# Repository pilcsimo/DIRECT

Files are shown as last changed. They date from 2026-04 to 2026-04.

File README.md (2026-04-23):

# DIRECT: Durable Intuitive Repeatable Ergonomic Control Device for Robot Teleoperation

This is the SW and HW repository of DIRECT. Visit the [website](https://pilcsimo.github.io/direct/index.html) for the paper and supplementary material.

DIRECT is an active teleoperation leader arm designed for continuous, large-scale robot data collection with [DROID](https://droid-dataset.github.io/). It serves as a drop-in alternative to VR controllers, offering a more intuitive experience for operators familiar with robot arms.

DIRECT builds on the hardware and software foundations of [FACTR](https://jasonjzliu.com/factr/) and draws mechanical inspiration from [GELLO](https://wuphilipp.github.io/gello_site/). It addresses three pain points encountered during sustained data collection: mechanical failures under continuous use, calibration drift between sessions, and operator fatigue during standing workflows.

> **Credits:**
> - Software and control architecture based on **FACTR** by Jason Jingzhou Liu and Yulong Li.
>   - Teleop software: [github.com/JasonJZLiu/FACTR_Teleop](https://github.com/JasonJZLiu/FACTR_Teleop)
>   - Hardware design: [github.com/JasonJZLiu/FACTR_Hardware](https://github.com/JasonJZLiu/FACTR_Hardware)
> - Mechanical gripper inspiration from **GELLO** by Philipp Wu et al.: [github.com/wuphilipp/gello_mechanical](https://github.com/wuphilipp/gello_mechanical)

---

## DIRECT Design

DIRECT prioritizes three principles for continuous data collection:

### Durability via Servo Shields

Active joint-space controllers that mount servos as load-bearing elements are vulnerable to thread pull-out, where mounting screws tear from the plastic servo housings under continuous use. DIRECT introduces 3D-printed enclosures that absorb and redirect structural loads away from the servos. Mechanical failures observed during testing occurred exclusively on 3D-printed parts, which can be reprinted on demand.

### Repeatability via Deterministic Calibration

Prior puppet-style controllers rely on a visual resting pose for calibration, which can drift between sessions and cause unstable gravity compensation. DIRECT introduces physical calibration fixtures that lock the device joints into a mechanical zero. The physical joint configuration at startup therefore matches the zero pose defined in the URDF, providing consistent initial conditions across episodes.

### Ergonomics for Standing Operation

DIRECT raises the base by 10 cm to extend the operator's reachable configuration space during the standing workflow typical of DROID. It also introduces the **Ergogrip** — a contoured handle inspired by lever-action grips — designed for single-handed standing operation during extended sessions.

### Printability and Sourcing

All structural parts are designed for 3D printing in PETG for improved toughness and temperature resistance. Pre-configured print files with correct part orientations are provided. The design uses standard screws included with the servos and an off-the-shelf metric ball bearing.

### Software Architecture

DIRECT uses a decoupled two-process architecture to integrate into data collection platforms without modifying their codebases. A standalone Python application runs a 500 Hz control loop managing device kinematics and gravity compensation. A lightweight plugin runs alongside the platform GUI, translating device states into joint commands. A de-sync state machine handles reconnection after trajectory resets: each reconnection triggers a smooth PD realignment before active control resumes.

### Force Feedback

Full bi-directional force feedback (as in FACTR) requires a tight control loop at hundreds of Hz between robot and device. Routing this through the DROID GUI (~50 Hz) introduces latency that destabilizes the loop. DIRECT therefore does not implement force feedback in this release. Instead, a local virtual spring on the device trigger provides passive resistance for grip comfort.

---

## Hardware

> **Assembly guide:** DIRECT does not yet have its own assembly documentation. Follow the **[FACTR Hardware assembly guide](https://github.com/JasonJZLiu/FACTR_Hardware)** (core arm structure, servo wiring, and BOM). The DIRECT-specific printed parts are drop-in additions that are self-explanatory once you have the base arm assembled.

DIRECT-specific parts are available in `hardware/`:
- **`hardware/step/`** — STEP (`.step`) source CAD files, for import into any CAD tool
- **`hardware/3mf/`** — 3MF (`.3mf`) print files pre-configured in **PrusaSlicer** with correct part orientations, supports, and material settings

Parts included:
- Servo shield enclosures — redirect structural loads away from servo housings
- Calibration fixtures (base wedge + joint wedge + trigger dock) — lock joints into mechanical zero
- Elevated base (+10 cm) — extends the operator's reachable configuration space
- Ergogrip handle — contoured for single-handed standing operation

All DIRECT parts are designed for **PETG** (recommended over PLA for toughness and temperature resistance). Pre-configured print orientations are included in the 3MF files. The design uses M2/M3 screws (included with the servos) and one standard metric ball bearing.

> **Important — weigh links before assembly:** `direct.urdf` encodes the mass and inertia of each link *with its servo already installed*. Weigh each printed link after inserting its servo (and any heat-set inserts/bearings) but *before* attaching it to the arm chain. Update the corresponding `<mass value="..."/>` entries in the URDF to match your measured values. Accurate link masses are critical for stable gravity compensation.
>
> **Note on URDF provenance:** The mass and inertia parameters in `direct.urdf` are taken directly from the FACTR project and have **not** been re-measured or recalculated for DIRECT. This means gravity compensation may exhibit some residual drift even after accurate mechanical calibration. If you require tighter gravity compensation, re-identify the link inertial parameters for your specific assembly.

---

## First Time Installation Guide

### Hardware Setup

- Follow the [FACTR Hardware assembly guide](https://github.com/JasonJZLiu/FACTR_Hardware) to build the base arm, then add the DIRECT-specific printed parts.
- Install DIRECT onto your DROID portable setup (power sources, USB, mounting via clamps/screws, cable management).
- Verify the device powers on and servos respond before proceeding.

### Software Setup — DROID's Data Collection Laptop

> Requires DROID to already be installed. If not, follow [droid-dataset.github.io](https://droid-dataset.github.io/) first.

Create a dedicated Conda environment with Python 3.10 to avoid dependency conflicts with the DROID GUI environment:

```bash
conda create -n teleop_direct python=3.10
conda activate teleop_direct
```

Follow the [Dynamixel servo setup guide](./src/direct/README.md) to configure servo IDs, baud rates, and USB latency.

Install [Pinocchio](https://stack-of-tasks.github.io/pinocchio/download.html) and then clone and install this package at the same level as the DROID repository:

```bash
conda activate teleop_direct
cd <path_to_repo_root>/DIRECT
pip install -e .
```

---

## Testing Before Using with DROID

Make sure the DIRECT device is powered on and connected to your laptop via USB.

```bash
conda activate teleop_direct
python DIRECT/scripts/run_direct.py --calib  # required on first run or after re-powering servos
```

This launches the DIRECT control loop and connects to the device. Follow the terminal prompts to calibrate. This process must be launched **before** the DROID GUI.

---

# Usage with DROID GUI — Teleoperator's Guide

## DIRECT Hardware Setup

- Plug DIRECT into the power outlet (white cable).
- Turn ON the switch on the blue Servo Control Board (mounted to the base of DIRECT). A red LED should illuminate, indicating servos are powered.
- Plug the Micro-USB cable from the PC into the Servo Control Board (U2D2 converter). A second red LED inside the box should illuminate, indicating USB connection.

## DIRECT Calibration

Before starting the DROID GUI, DIRECT must be calibrated. Insert the calibration fixtures to lock the device into its mechanical zero position, which corresponds to the Franka Emika Panda robot arm zero pose.

The compound figure below shows the device fully assembled with all calibration fixtures inserted, from three angles:

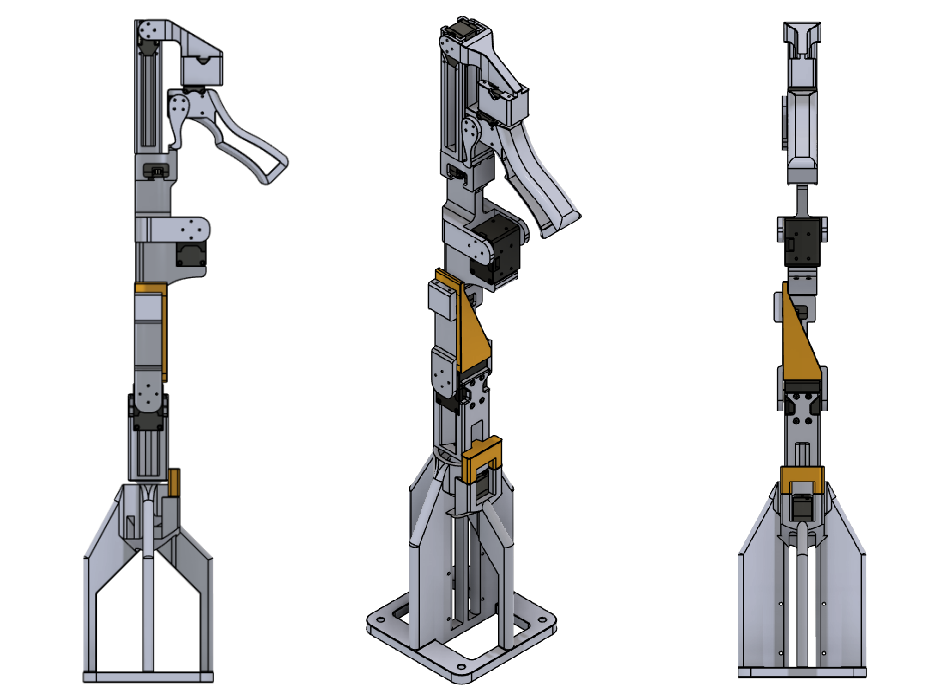
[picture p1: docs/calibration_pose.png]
DIRECT in calibration (zero) position — front, side, and 3/4 views


> **Wrist camera:** The wrist-mounted camera mounts on the **side of the Ergogrip handle**. Ensure it is attached before calibrating so its cable routing does not shift the device out of the locked position.

Fixtures to insert before calibrating:
- **Base wedge** (black) — locks the base joint
- **Joint wedge** (orange) — inserted between links to lock the mid-chain joints
- **Trigger dock** — trigger rested against the notch on link 4 (small white arrow marker)

Open the 1st terminal and run:

```bash
conda activate teleop_direct
python DIRECT/scripts/run_direct.py --calib  # IMPORTANT: --calib is required every time servo power is cycled
```

The script will exit with an error if the USB latency timer is not set. Follow the printed instruction to fix it (needs `sudo`):

```bash
echo 1 | sudo tee /sys/bus/usb-serial/devices/ttyUSB0/latency_timer
```

Run the calibration command again after setting the timer. This is required every time servo power is cycled.

Calibration procedure:
1. Insert the calibration fixtures as shown above — this locks the device into its mechanical zero.
2. Press **Enter** at the first prompt. Remove the calibration fixtures.
3. At the second prompt you set the null-space (redundancy resolution) target. Position the device where desired, then press **Enter**. DIRECT will automatically hold this configuration when redundancy is available.

The calibration is saved to a `.npy` file beside the config. On subsequent runs without `--calib`, the saved calibration is loaded automatically (as long as servo power was not cycled).

## After Calibration — Starting the Control Loop

DIRECT will enter gravity compensation mode automatically after calibration. Leave this terminal running.

To start in a subsequent session (servo power not cycled):

```bash
conda activate teleop_direct
python DIRECT/scripts/run_direct.py
```

---

## Dry-Run — Test DIRECT Without the Robot

Before launching the full DROID GUI (which sends live commands to the Franka), you can dry-run the policy to verify DIRECT is communicating correctly and the policy initialises without errors:

```bash
conda activate teleop_direct
python DIRECT/scripts/debug_direct_policy.py
```

This script initialises `DIRECTTeleopPolicy` and loops `policy.forward()` at 10 Hz using a fixed observation set to the DROID Franka rest pose. No robot connection is required. Use it to confirm ZMQ addresses, keyboard handling, and policy state logic before risking live hardware.

---

## Running DROID GUI with DIRECT

Pre-flight checklist:

- Franka robot is powered on (yellow), unlocked (white button glowing blue), and in FCI mode.
- Robot is connected to the Polymetis Control Robot PC.
- All ZED cameras are powered and connected to the Data Collection PC.
- DIRECT control loop is running in the 1st terminal (step above).
- ChArUco calibration board is ready for the DROID camera calibration procedure.

Open a 2nd terminal for the DROID GUI:

```bash
conda activate teleop_droid
python DIRECT/scripts/main.py --direct
```

### Keyboard Controls

| Key | Action |
|-----|---|
| `F5` | Toggle all inputs ON/OFF (lock-out to prevent accidental commands) |
| `A` | Pulse success signal |
| `B` | Pulse failure signal |
| `M` | Toggle movement ON/OFF — enables/disables sending joint commands to robot |
| `N` | Set null-space target to current device position |
| `V` | Toggle torque visualisation |
| `F` | Cycle feedback mode (OFF → ALIGNED_TORQUE) |
| `Shift` | Toggle camera views in DROID GUI |

**When enabling movement (`M`):** DIRECT first syncs to the robot's current position. Do not resist — let it settle before moving. You will feel the device actively move to match the robot; wait until it stops before starting teleoperation.

**When setting null-space (`N`):** DIRECT will automatically drift toward this joint configuration whenever redundancy is available (without moving the end-effector).

### Recording Trajectories

1. Make sure **movement is disabled** first.
2. Press `A` to start recording. Wait for camera feeds and the robot to reach its start position.
3. After camera feeds appear, press `M` to enable movement and begin teleoperation.

---

## Known Issues and Planned Improvements

### Known Issues

- Sync via `M` key can occasionally be unreliable in the DROID GUI — under investigation.
- No end-effector safety workspace — the robot can reach itself or surrounding objects.
- Gripper virtual spring can bounce at the end of its range of motion.

### Planned Improvements

- Force feedback: detect external joint torques on the robot and relay them to the device (framework is present, tuning required).
- End-effector safety bounding box via IK on the DIRECT side.

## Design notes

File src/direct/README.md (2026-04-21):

# Setting up Dynamixel Servos

> **Attribution:** The servo setup instructions below are adapted directly from the
> [FACTR Teleop README](https://github.com/JasonJZLiu/FACTR_Teleop/blob/main/src/factr_teleop/README.md)
> (© FACTR authors, Apache 2.0). Follow that guide through the
> **"Setting up Dynamixel Servos"** section (servo IDs, baud rate, and USB latency).
> **Stop before "Preparing to Launch FACTR Teleop"** — DIRECT uses a different
> calibration and launch procedure. Return to the [main README](../../README.md)
> for those steps.

Before using DIRECT, the leader arm's Dynamixel servos need to be properly
configured. Please install the [Dynamixel Wizard](https://emanual.robotis.com/docs/en/software/dynamixel/dynamixel_wizard2/)
software.

## Update Servo IDs

By default, all Dynamixel servos are set to ID 1. To control multiple servos with a single U2D2 controller,
each servo must be assigned a unique ID. This assignment should be done one servo at a time, starting with
the servo closest to the robot base and progressing up the kinematic chain. Assign IDs sequentially from
1 up to 8, with the gripper trigger servo holding ID 8.

### Steps to Change a Servo's ID

1. **Connect a single servo to the U2D2 controller.**
2. **Launch the Dynamixel Wizard software.**
3. **Configure the scanning settings:**
   - In the top menu bar, go to **Tools → Options**.
   - Under **"Select port to scan"**, ensure all ports are selected.
   - Under **"Select baudrate to scan"**, choose the correct baudrate. The default is **57600 bps**. If unsure, select all available options.
   - Under **"Set ID range to scan"**, you can speed up scanning by limiting the range to **0–15**, unless the servo might already have an ID outside this range.
4. **Click the Scan icon** (magnifying glass with a gear) in the top-left corner.
   - If the servo is found, it will appear in the left panel of the window.
5. **Select the detected servo** from the panel, then click **ID** found in the middle panel of the window.
   - Select the new ID on the right panel of the window and click **Save**.
6. **Repeat** the above steps for each servo.

## Increase Servo Control Frequency

There are additional Dynamixel servo settings that must be changed in order to run the control loop at
a frequency as fast as 500Hz. The steps for each servo are as follows:

### Steps to Increase Servo Control Frequency

1. **Launch the Dynamixel Wizard software** and **scan for servos**.
2. **Select each detected servo** from the left-hand panel.
3. In the middle panel, click **"Baud Rate (Bus)"**:
   - On the right-hand panel, **set the value to 4 Mbps** and click **Save**.
4. In the middle panel, click **"Return Delay Time"**:
   - On the right-hand panel, **set the value to 0** and click **Save**.

In addition to the Dynamixel servo settings, it is crucial to minimize the latency of the USB port connected to the U2D2 controller
to achieve high-frequency control. The latency timer should be set to `1` for optimal performance.

### Steps to Check and Set USB Port Latency

1. **List connected U2D2 devices**:

   ```bash
   ls /dev/serial/by-id/
   ```

   This will show device names for each connected U2D2 controller. For example:

   ```
   usb-FTDI_USB__-__Serial_Converter_FT7WBF8S-if00-port0
   usb-FTDI_USB__-__Serial_Converter_FT951EJA-if00-port0
   ```

   Identify the one corresponding to your **leader arm**. Replace `<device-name>` with the correct name in the next steps.

2. **Resolve the full path to the USB device**:

   ```bash
   readlink -f /dev/serial/by-id/<device-name>
   ```

   This will return something like:

   ```
   /dev/ttyUSB0
   ```

3. **Check the current latency timer value**:

   ```bash
   cat /sys/bus/usb-serial/devices/<ttyUSBx>/latency_timer
   ```

   Replace `<ttyUSBx>` with the ttyUSB device name from the previous step (e.g., `ttyUSB0`).

4. **If the value is not `1`, set it manually**:

   ```bash
   echo 1 | sudo tee /sys/bus/usb-serial/devices/<ttyUSBx>/latency_timer
   ```

   > **Note:** This command requires `sudo` permissions.

   > **Note:** Everytime the U2D2 controller USB is re-plugged into the computer, this command needs to be run again to ensure the
   latency timer is 1.

### Automated Latency Check

Note that the provided leader arm node **automatically checks** the latency timer on startup.
It reads the `dynamixel_port` from the YAML config file and verifies that the latency timer is set to `1`.

If the latency is not correctly set, the script will:

- Raise an exception
- Output the exact `echo` command required to fix it

Since changing the latency timer requires `sudo` permissions, **you must run the command manually** when prompted.

---

For configuration, calibration, and usage instructions see the [main README](../../README.md).

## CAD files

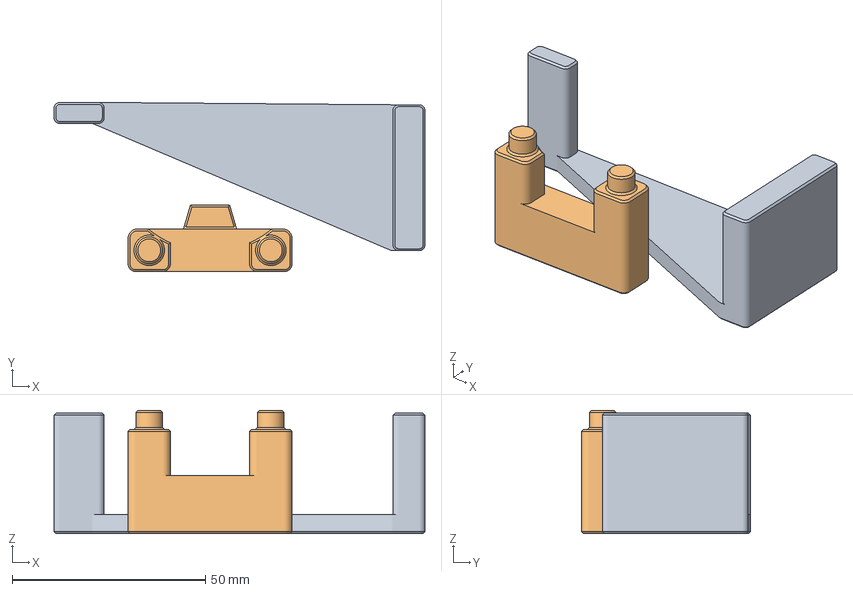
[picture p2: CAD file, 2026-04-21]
hardware/3mf/direct_calibration_fixtures.3mf
96.1 x 43.8 x 31.9 mm
calibration_fixture
calibration_fixture_base

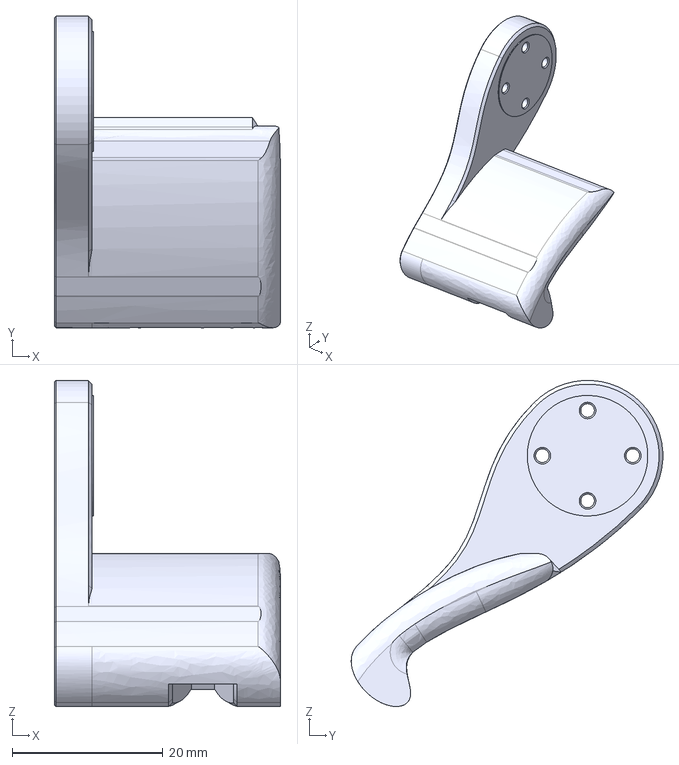
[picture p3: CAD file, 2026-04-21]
hardware/step/direct_ergogrip_trigger.step
30.0 x 41.4 x 43.3 mm

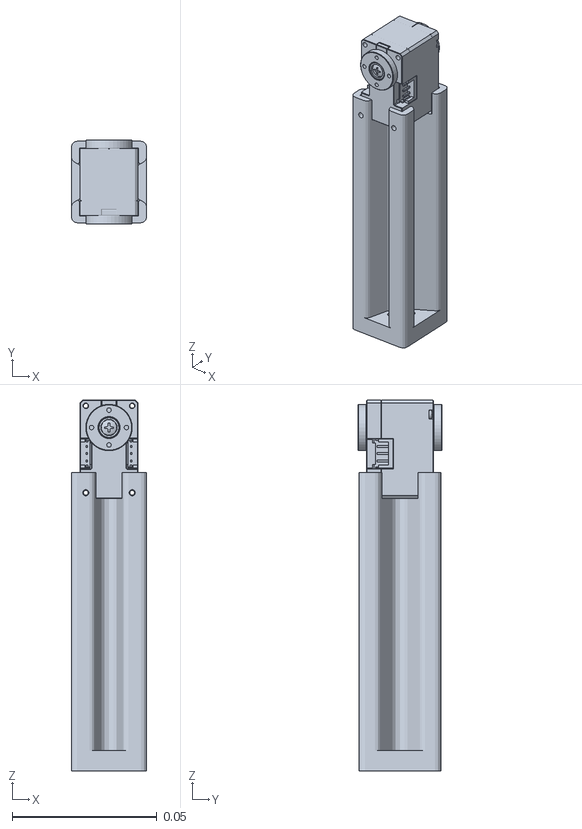
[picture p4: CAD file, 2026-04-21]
src/direct/direct_teleop/urdf/meshes/link_5.STL
0.026 x 0.029 x 0.128

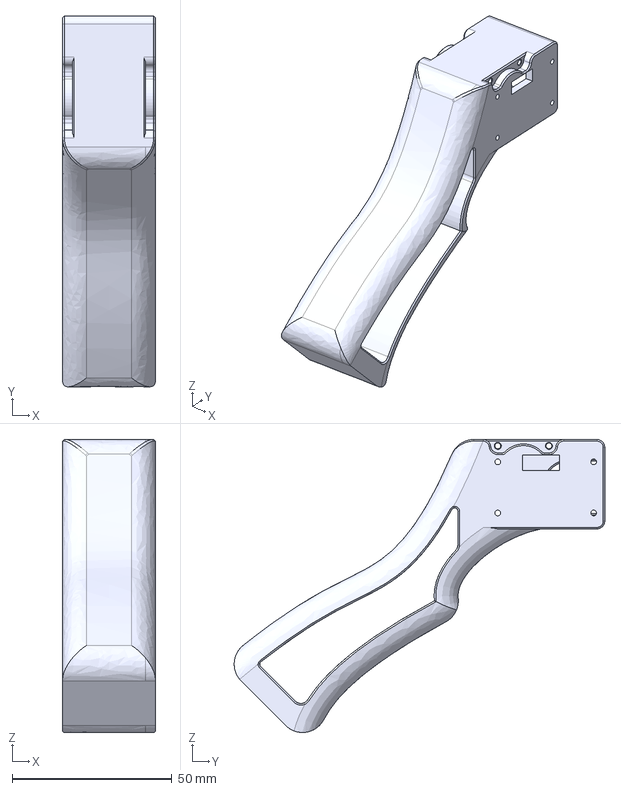
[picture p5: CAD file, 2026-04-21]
hardware/step/direct_ergogrip_body.step
29.0 x 116.0 x 91.7 mm

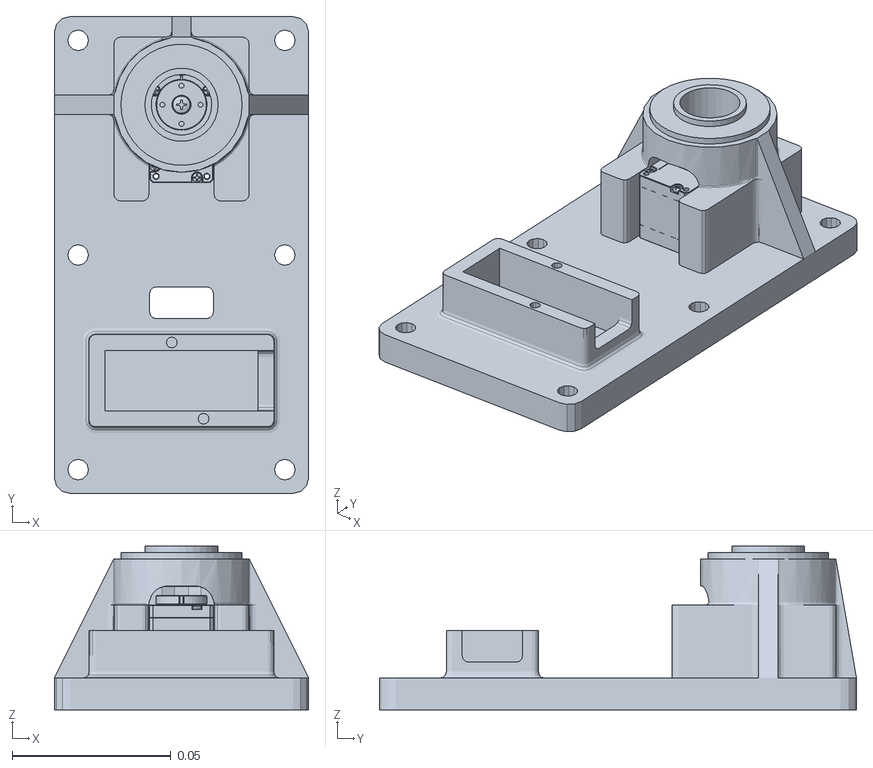
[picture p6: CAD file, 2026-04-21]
src/direct/direct_teleop/urdf/meshes/base_link.STL
0.08 x 0.15 x 0.0515

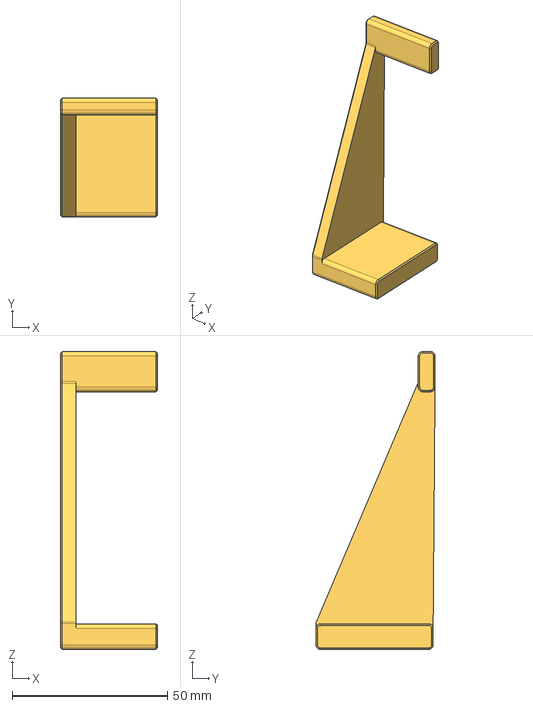
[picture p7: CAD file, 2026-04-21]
hardware/step/calibration_fixture.step
31.2 x 38.4 x 96.1 mm

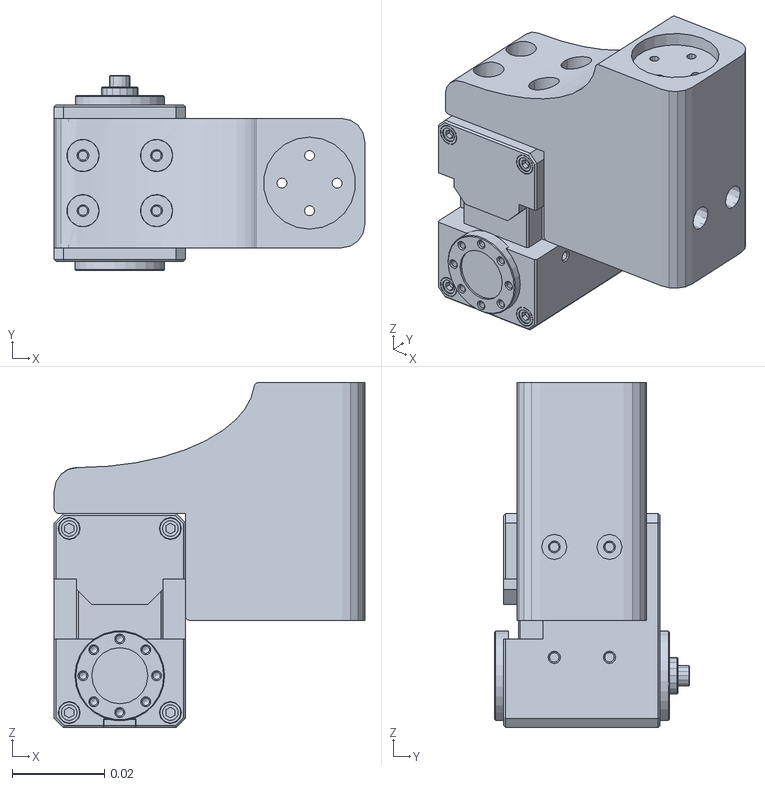
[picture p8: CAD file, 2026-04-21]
src/direct/direct_teleop/urdf/meshes/link_3.STL
0.0675 x 0.0424 x 0.075

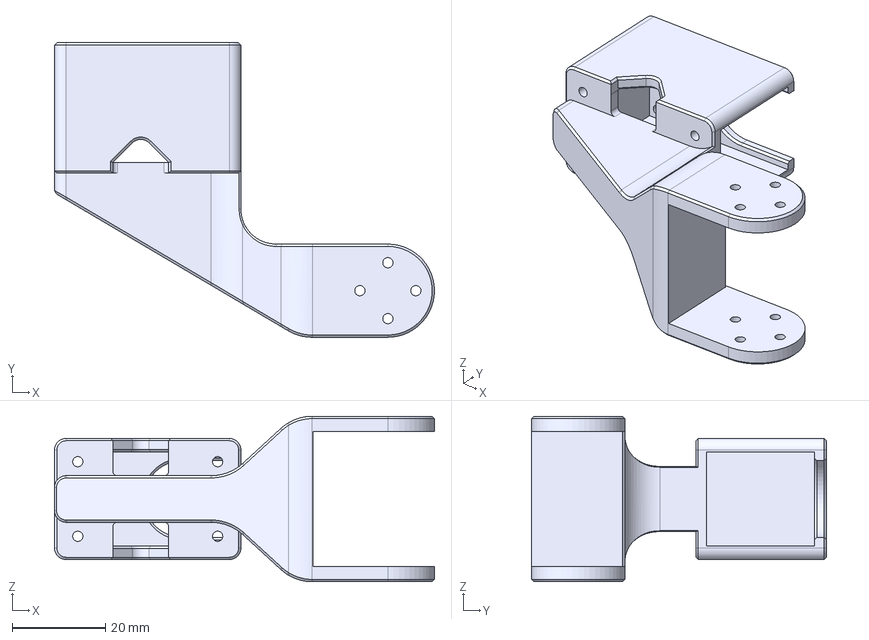
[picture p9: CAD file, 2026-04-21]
hardware/step/direct_link_6.step
81.5 x 63.2 x 35.5 mm

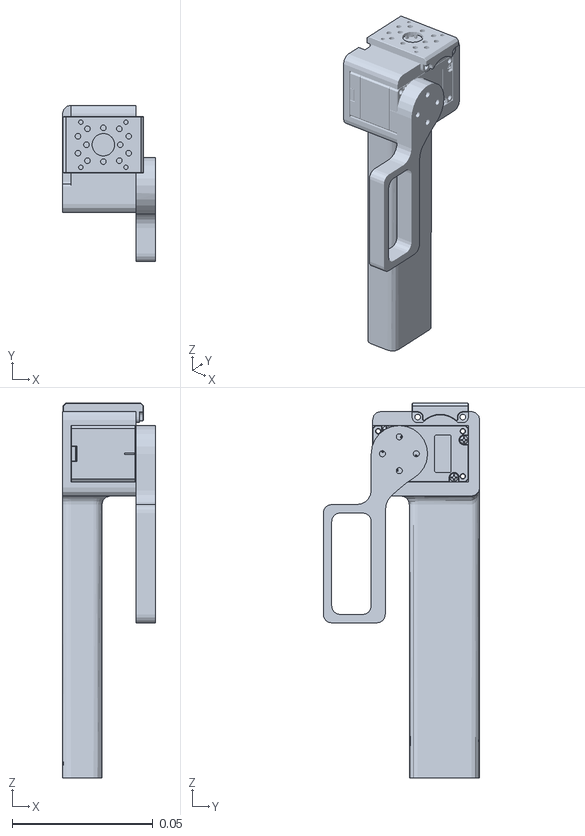
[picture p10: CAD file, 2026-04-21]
src/direct/direct_teleop/urdf/meshes/link_7.STL
0.033 x 0.0555 x 0.133

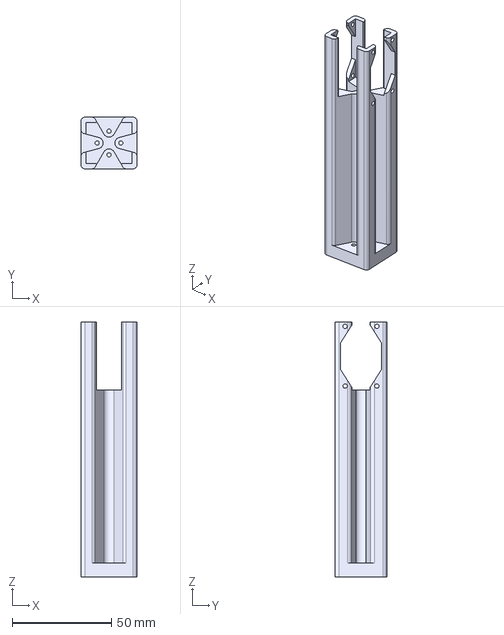
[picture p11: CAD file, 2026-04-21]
hardware/step/direct_link_5.step
28.2 x 26.0 x 128.2 mm

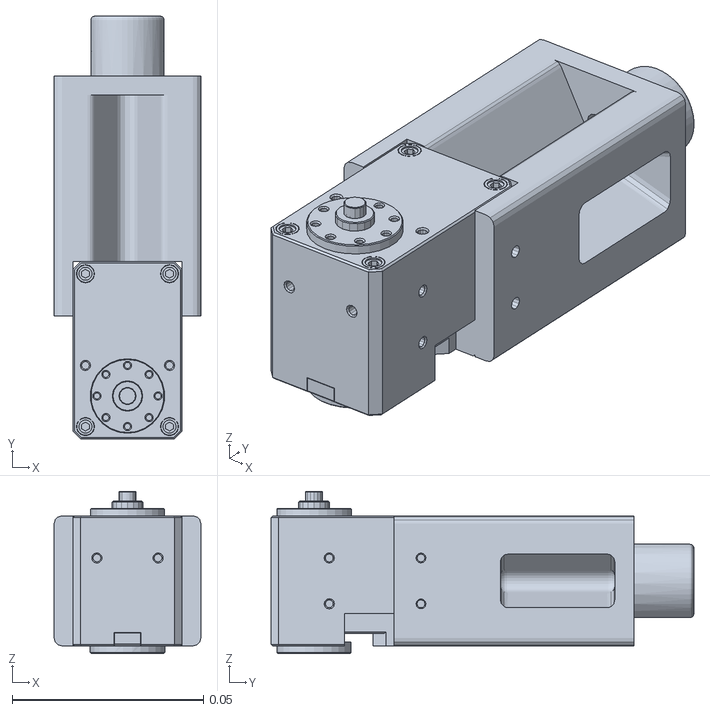
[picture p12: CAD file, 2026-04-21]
src/direct/direct_teleop/urdf/meshes/link_1.STL
0.0384 x 0.111 x 0.0424

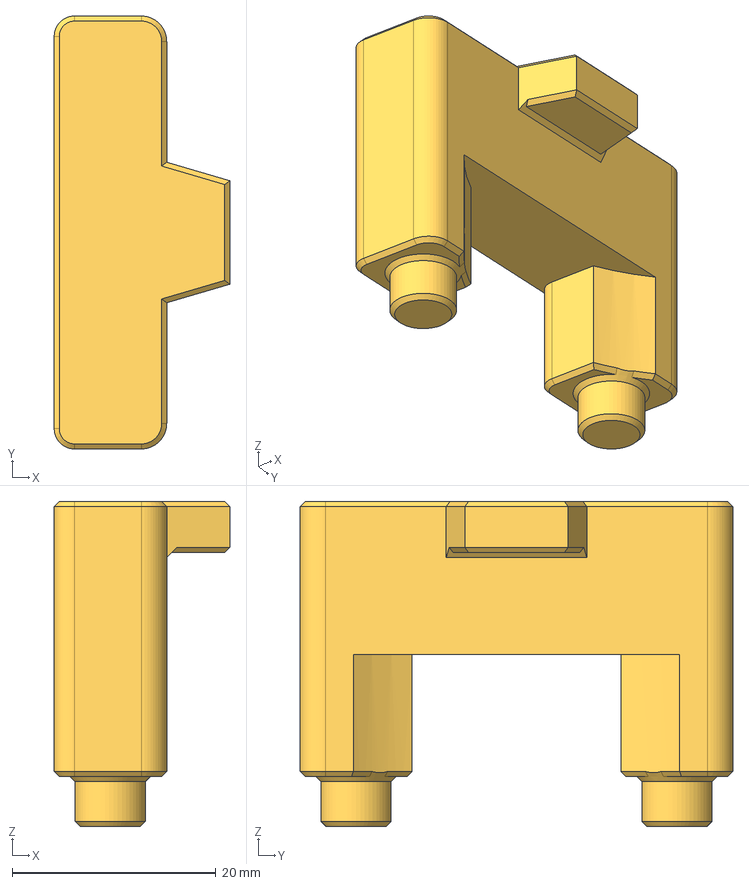
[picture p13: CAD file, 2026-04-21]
hardware/step/calibration_fixture_base.step
17.2 x 42.5 x 31.9 mm

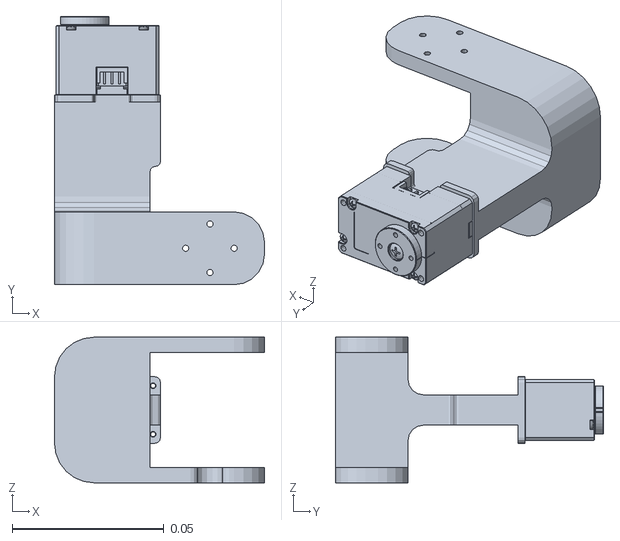
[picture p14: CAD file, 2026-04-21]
src/direct/direct_teleop/urdf/meshes/link_4.STL
0.0692 x 0.0885 x 0.048

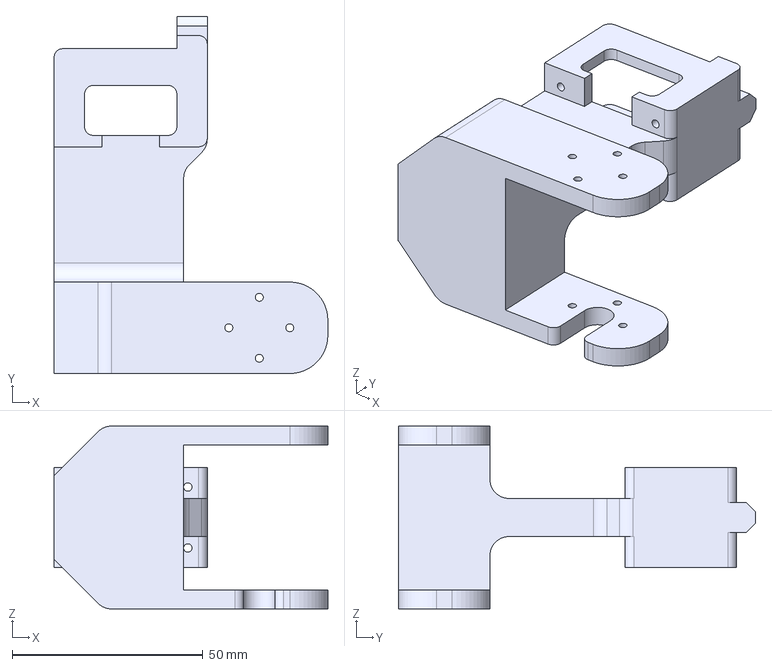
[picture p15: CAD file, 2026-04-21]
hardware/step/direct_link_4.step
71.8 x 93.7 x 48.0 mm

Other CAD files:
src/direct/direct_teleop/urdf/meshes/link_6.STL
hardware/step/direct_link_2.step
src/direct/direct_teleop/urdf/meshes/link_2.STL
hardware/step/direct_link_1.step
hardware/step/base.step
hardware/step/direct_link_3.step

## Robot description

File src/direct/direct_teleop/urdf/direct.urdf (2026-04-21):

<?xml version="1.0" encoding="utf-8"?>
<robot name="direct_teleop_franka">
  <link name="base_link">
    <inertial>
      <origin xyz="-0.00011 -0.02855 0.01863" rpy="0 0 0" />
      <mass value="0.215" />
      <inertia ixx="0.00042191703999999995" ixy="-1.4126099999999999e-06" ixz="3.381e-08" iyy="0.00013079891" iyz="-7.026067e-05" izz="0.00044713047" />
    </inertial>
    <visual>
      <origin xyz="0 0 0" rpy="0 0 0" />
      <geometry>
        <mesh filename="meshes/base_link.STL" />
      </geometry>
      <material name="">
        <color rgba="0.49804 0.49804 0.49804 1" />
      </material>
    </visual>
    <collision>
      <origin xyz="0 0 0" rpy="0 0 0" />
      <geometry>
        <mesh filename="meshes/base_link.STL" />
      </geometry>
    </collision>
  </link>
  <link name="link_1">
    <inertial>
      <origin xyz="0.0 0.02439 0.0004" rpy="0 0 0" />
      <mass value="0.115" />
      <inertia ixx="8.901396e-05" ixy="-0.0" ixz="-0.0" iyy="2.125741e-05" iyz="5.9353e-07" izz="8.784972e-05" />
    </inertial>
    <visual>
      <origin xyz="0 0 0" rpy="0 0 0" />
      <geometry>
        <mesh filename="meshes/link_1.STL" />
      </geometry>
      <material name="">
        <color rgba="0.50196 0.50196 0.50196 1" />
      </material>
    </visual>
    <collision>
      <origin xyz="0 0 0" rpy="0 0 0" />
      <geometry>
        <mesh filename="meshes/link_1.STL" />
      </geometry>
    </collision>
  </link>
  <joint name="joint_1" type="revolute">
    <origin xyz="0 0 0.13525" rpy="-1.5708 0 0" />
    <parent link="base_link" />
    <child link="link_1" />
    <axis xyz="0 -1 0" />
    <limit lower="-2.8973" upper="2.8973" effort="0.92" velocity="6.8" />
  </joint>
  <link name="link_2">
    <inertial>
      <origin xyz="5e-05 -0.00563 0.05863" rpy="0 0 0" />
      <mass value="0.0521" />
      <inertia ixx="4.888724e-05" ixy="-5.247e-08" ixz="1.1211e-07" iyy="4.3692040000000004e-05" iyz="2.74388e-06" izz="8.3539e-06" />
    </inertial>
    <visual>
      <origin xyz="0 0 0" rpy="0 0 0" />
      <geometry>
        <mesh filename="meshes/link_2.STL" />
      </geometry>
      <material name="">
        <color rgba="0.50196 0.50196 0.50196 1" />
      </material>
    </visual>
    <collision>
      <origin xyz="0 0 0" rpy="0 0 0" />
      <geometry>
        <mesh filename="meshes/link_2.STL" />
      </geometry>
    </collision>
  </link>
  <joint name="joint_2" type="revolute">
    <origin xyz="0 0 0" rpy="1.5708 0 0" />
    <parent link="link_1" />
    <child link="link_2" />
    <axis xyz="0 1 0" />
    <limit lower="-1.7628" upper="1.7628" effort="0.92" velocity="6.8" />
  </joint>
  <link name="link_3">
    <inertial>
      <origin xyz="-0.03382 0.00041 -0.04571" rpy="0 0 0" />
      <mass value="0.113" />
      <inertia ixx="4.4500849999999996e-05" ixy="3.4593000000000003e-07" ixz="-1.575217e-05" iyy="6.479292e-05" iyz="2.9787e-07" izz="4.1141010000000005e-05" />
    </inertial>
    <visual>
      <origin xyz="0 0 0" rpy="0 0 0" />
      <geometry>
        <mesh filename="meshes/link_3.STL" />
      </geometry>
      <material name="">
        <color rgba="0.50196 0.50196 0.50196 1" />
      </material>
    </visual>
    <collision>
      <origin xyz="0 0 0" rpy="0 0 0" />
      <geometry>
        <mesh filename="meshes/link_3.STL" />
      </geometry>
    </collision>
  </link>
  <joint name="joint_3" type="revolute">
    <origin xyz="0 0 0.09425" rpy="-3.1416 0 3.1416" />
    <parent link="link_2" />
    <child link="link_3" />
    <axis xyz="0 0 -1" />
    <limit lower="-2.8973" upper="2.8973" effort="0.92" velocity="6.8" />
  </joint>
  <link name="link_4">
    <inertial>
      <origin xyz="-0.03202 0.032420000000000004 0.00013000000000000002" rpy="0 0 0" />
      <mass value="0.0565" />
      <inertia ixx="5.129189e-05" ixy="3.7090300000000004e-06" ixz="-2.1098e-07" iyy="1.417375e-05" iyz="2.4664e-07" izz="5.412985e-05" />
    </inertial>
    <visual>
      <origin xyz="0 0 0" rpy="0 0 0" />
      <geometry>
        <mesh filename="meshes/link_4.STL" />
      </geometry>
      <material name="">
        <color rgba="0.50196 0.50196 0.50196 1" />
      </material>
    </visual>
    <collision>
      <origin xyz="0 0 0" rpy="0 0 0" />
      <geometry>
        <mesh filename="meshes/link_4.STL" />
      </geometry>
    </collision>
  </link>
  <joint name="joint_4" type="revolute">
    <origin xyz="-0.04125 0 -0.06374" rpy="-1.5708 0 -3.1416" />
    <parent link="link_3" />
    <child link="link_4" />
    <axis xyz="0 0 1" />
    <limit lower="-3.0718" upper="0" effort="0.92" velocity="6.8" />
  </joint>
  <link name="link_5">
    <inertial>
      <origin xyz="0.0 0.0001 0.07795999999999999" rpy="0 0 0" />
      <mass value="0.0542" />
      <inertia ixx="7.589592e-05" ixy="5.1e-10" ixz="2.8199999999999998e-09" iyy="7.49895e-05" iyz="-1.6106000000000001e-07" izz="5.4057600000000006e-06" />
    </inertial>
    <visual>
      <origin xyz="0 0 0" rpy="0 0 0" />
      <geometry>
        <mesh filename="meshes/link_5.STL" />
      </geometry>
      <material name="">
        <color rgba="0.50196 0.50196 0.50196 1" />
      </material>
    </visual>
    <collision>
      <origin xyz="0 0 0" rpy="0 0 0" />
      <geometry>
        <mesh filename="meshes/link_5.STL" />
      </geometry>
    </collision>
  </link>
  <joint name="joint_5" type="revolute">
    <origin xyz="-0.04125 0.0735 0" rpy="-1.5708 0 0" />
    <parent link="link_4" />
    <child link="link_5" />
    <axis xyz="0 0 1" />
    <limit lower="-2.8973" upper="2.8973" effort="0.92" velocity="6.8" />
  </joint>
  <link name="link_6">
    <inertial>
      <origin xyz="0.04378 -0.02846 0.0" rpy="0 0 0" />
      <mass value="0.0483" />
      <inertia ixx="1.1852440000000001e-05" ixy="6.85499e-06" ixz="-1.4199999999999999e-09" iyy="1.1023870000000001e-05" iyz="1.6200000000000002e-09" izz="1.958864e-05" />
    </inertial>
    <visual>
      <origin xyz="0 0 0" rpy="0 0 0" />
      <geometry>
        <mesh filename="meshes/link_6.STL" />
      </geometry>
      <material name="">
        <color rgba="0.50196 0.50196 0.50196 1" />
      </material>
    </visual>
    <collision>
      <origin xyz="0 0 0" rpy="0 0 0" />
      <geometry>
        <mesh filename="meshes/link_6.STL" />
      </geometry>
    </collision>
  </link>
  <joint name="joint_6" type="revolute">
    <origin xyz="0 0 0.1185" rpy="1.5708 0 0" />
    <parent link="link_5" />
    <child link="link_6" />
    <axis xyz="0 0 1" />
    <limit lower="-0.0175" upper="3.7525" effort="0.92" velocity="6.8" />
  </joint>
  <link name="link_7">
    <inertial>
      <origin xyz="-0.0009599999999999999 -0.00564 -0.03933" rpy="0 0 0" />
      <mass value="0.056" />
      <inertia ixx="6.82626e-05" ixy="2.19768e-06" ixz="-4.663569999999999e-06" iyy="6.539764e-05" iyz="4.19546e-06" izz="1.085574e-05" />
    </inertial>
    <visual>
      <origin xyz="0 0 0" rpy="0 0 0" />
      <geometry>
        <mesh filename="meshes/link_7.STL" />
      </geometry>
      <material name="">
        <color rgba="0.25098 0.25098 0.25098 1" />
      </material>
    </visual>
    <collision>
      <origin xyz="0 0 0" rpy="0 0 0" />
      <geometry>
        <mesh filename="meshes/link_7.STL" />
      </geometry>
    </collision>
  </link>
  <joint name="joint_7" type="revolute">
    <origin xyz="0.04402 -0.0535 0" rpy="-1.5708 0 0" />
    <parent link="link_6" />
    <child link="link_7" />
    <axis xyz="0 0 -1" />
    <limit lower="-2.8973" upper="2.8973" effort="0.92" velocity="6.8" />
  </joint>
</robot>

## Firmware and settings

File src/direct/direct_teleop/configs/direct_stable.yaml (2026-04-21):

dynamixel:
  # USB port name — find yours with: ls /dev/serial/by-id/
  dynamixel_port: "usb-FTDI_USB__-__Serial_Converter_XXXXXXXX-if00-port0"
  # Servo types
  servo_types:
    [
      "XC330_T288_T",
      "XM430_W210_T",
      "XC330_T288_T",
      "XM430_W210_T",
      "XC330_T288_T",
      "XC330_T288_T",
      "XC330_T288_T",
      "XC330_T288_T",
    ]
  # Servo joint directions to match that of the leader arm
  joint_signs: [1, 1, 1, -1, 1, -1, 1, 1]

arm_teleop:
  # URDF used for creating leader arm dynamics model to compute gravity compensation
  leader_urdf: "direct.urdf"
  num_arm_joints: 7
  # Low-pass filter alpha for smoothing joint position commands
  low_pass_alpha: 0.1
  arm_joint_limits_max: [2.8973, 1.7628, 2.8973, 0, 2.8973, 3.7525, 2.8973]
  arm_joint_limits_min:
    [-2.8973, -1.7628, -2.8973, -3.0718, -2.8973, -0.0175, -2.8973]
  arm_joint_limits_safety_margin: 0.1
  initialization:
    # The leader arm posture used to align the follower before enabling teleop
    initial_match_joint_pos: [0.0, -0.54763114, 0.0, -1.96963133,  0.0, 1.44807786, 0.0]

gripper_teleop:
  # Low-pass filter alpha for smoothing gripper commands
  low_pass_alpha: 0.1
  # Gripper actuation range
  actuation_range: 1.0
  # Gripper joint limits
  gripper_joint_limits: [0.0, 1.0]

controller:
  frequency: 500
  torque_feedback:
    enable: False  # Force feedback disabled in this release (see README for rationale)
    gain: 3.0
    damping: 0.035
    motor_scalar: 94.5652173913

  gravity_comp:
    enable: True
    gain: 0.775
  null_space_regulation:
    null_space_joint_target: [-0.13935425877571106,-0.020481698215007782,-0.05201413854956627,-2.0691256523132324,0.05058913677930832,2.0028650760650635,-0.9167874455451965]
    kp: 0.1  
    kd: 0.01
  static_friction_comp:
    enable_speed: 0.9
    gain: 0.2
  joint_limit_barrier:
    kp: 0.5
    kd: 0.025
  joint_position_control:
    interpolation_step_size: 0.5
    kp: 0.6
    kd: 0.02

  gripper_feedback: # attention this is THE VIRTUAL SPRING ON THE GRIPPER
    enable: True
    gain: 0.2
    damping: 0.1
